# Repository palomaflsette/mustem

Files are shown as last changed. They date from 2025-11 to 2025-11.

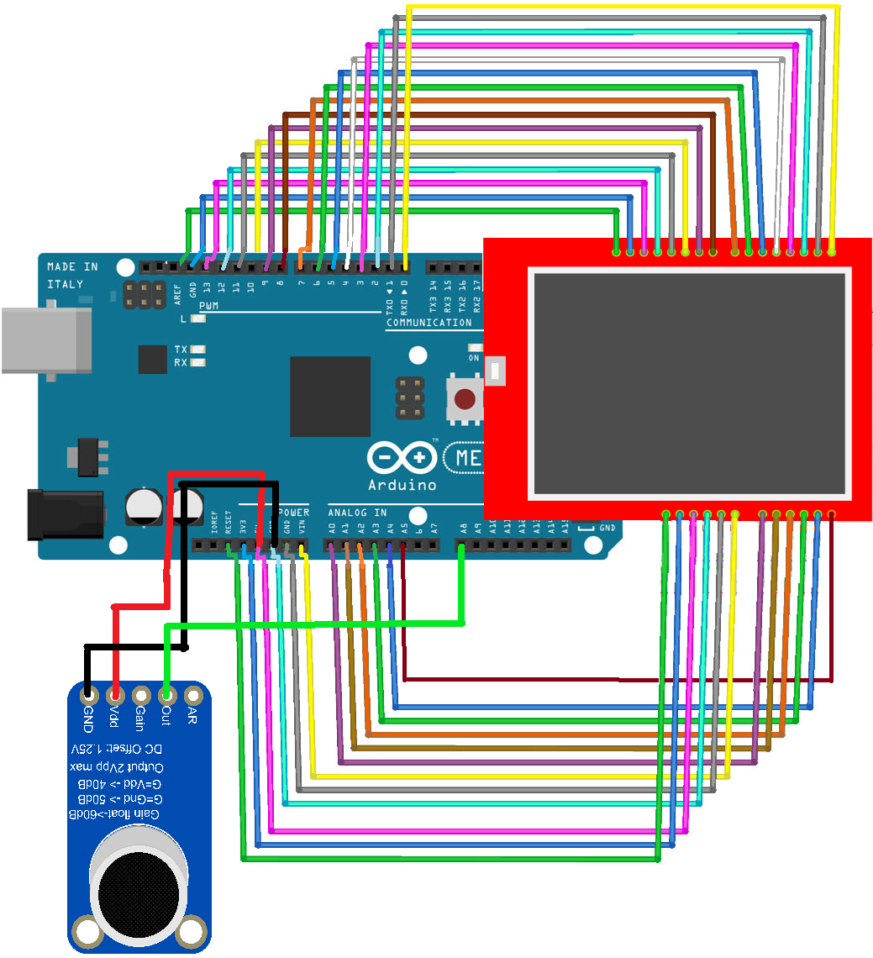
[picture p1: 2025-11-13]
hardware/schematics/mega_LCD_eletreto.png

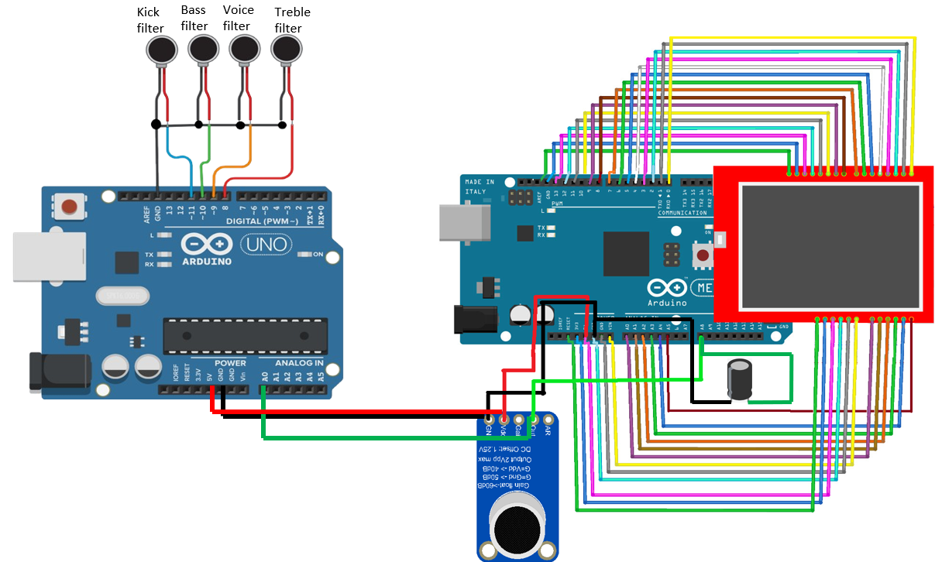
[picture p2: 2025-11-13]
hardware/schematics/integrated_system.png

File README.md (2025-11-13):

<div align="center">

# 🎵 MUSTEM
### Music - Multisensory Emotional Translation

**A scientifically-grounded dual-modality system for vibrotactile and visual translation of music as an assistive technology**






**[📖 Documentation](#-documentation) • [🚀 Quick Start](#-quick-start) • [🎥 Demos](#-video-demonstrations) • [📚 Research](#-research-paper)**

</div>

---

## 📑 Table of Contents

- [Overview](#-overview)
- [The Central Question](#-the-central-question)
- [System Architecture](#-system-architecture)
  - [Hardware Components](#hardware-components)
  - [Dual-Modality Design](#dual-modality-design)
- [Scientific Foundations](#-scientific-foundations)
  - [Stevens' Power Law](#1-stevens-power-law-psychoacoustic-scaling)
  - [Logarithmic Frequency Mapping](#2-logarithmic-frequency-mapping)
  - [Golden Ratio Phyllotaxis](#3-golden-ratio-phyllotaxis)
- [Repository Structure](#-repository-structure)
- [Getting Started](#-getting-started)
  - [Hardware Setup](#hardware-setup)
  - [Firmware Installation](#firmware-installation)
  - [Software Installation](#software-installation)
- [Video Demonstrations](#-video-demonstrations)
- [Research Paper](#-research-paper)
- [Technical Details](#-technical-details)
- [Bill of Materials](#-bill-of-materials)
- [License](#-license)
- [Citation](#-citation)
- [Acknowledgments](#-acknowledgments)

---

## 🎯 Overview

**MUSTEM** (Music - Multisensory Emotional Translation) is an open-source assistive technology that makes music accessible to deaf and hard-of-hearing individuals through complementary dual-modality translation:

- **Vibrotactile (FEEL):** 4-channel spatial frequency mapping for rhythm and foundation
- **Visual (SEE):** Mathematical color and pattern generation for structure and details

### Why MUSTEM?

- **430+ million** people worldwide are deaf or hard-of-hearing (WHO, 2023)
- Music represents **cultural and emotional exclusion**, not just auditory inaccessibility
- Current solutions (amplification, visual-only, vibration-only) have significant limitations
- **No integrated dual-modality approach** exists with scientific grounding

### Key Features

**Scientifically-grounded** - Based on Stevens' Power Law, Fletcher-Munson curves, and golden ratio  
**Real-time processing** - <60ms latency on affordable hardware  
**Affordable** - <$50 USD in components  
**Open-source** - Hardware, firmware, and software freely available  
**Validated** - Pilot study (N=7) with positive preliminary results  

---

## The Central Question

> **"Can deaf people *truly* experience music emotionally through non-auditory modalities?"**

**Our answer:** Musical experience is **relative to individual sensory capacity**. A deaf person experiencing music through tactile and visual modalities is not having an "inferior" experience—they're having an **authentic experience through their perceptual reality**.

Read our complete philosophical framework: **[docs/PHILOSOPHICAL_FRAMEWORK.md](docs/PHILOS_FRAMEWORK.md)**

### Core Arguments:

1. **Musical emotion emerges from pattern processing**, not specific sensory modality
2. **Deaf individuals have adapted sensory systems** with enhanced tactile and visual capabilities
3. **Validity is user-determined**, not defined by hearing-centric assumptions

---

## 🏗️ System Architecture

### Hardware Components
```
┌─────────────┐
│  Ambient    │
│   Sound     │
└──────┬──────┘
       │
       ▼
┌─────────────┐
│  Electret   │
│ Microphone  │
└──────┬──────┘
       │
       ├──────────────────────┬─────────────────────┐
       │                      │                     │
       ▼                      ▼                     ▼
┌─────────────┐      ┌─────────────┐      ┌─────────────┐
│  Arduino    │      │  Arduino    │      │   Python    │
│    UNO      │      │    Mega     │      │  Dashboard  │
│ (Tactile)   │      │  (Visual)   │      │ (Education) │
└──────┬──────┘      └──────┬──────┘      └─────────────┘
       │                     │
       ▼                     ▼
┌─────────────┐      ┌─────────────┐
│ 4× Motors   │      │ TFT LCD     │
│ (Wrists)    │      │  Display    │
└─────────────┘      └─────────────┘
```

### Dual-Modality Design

| Modality | Purpose | Hardware | Key Features |
|---|---|---|---|
| **Vibrotactile** | Rhythm & Foundation | 4× ERM motors | - Psychoacoustic band separation<br>- Stevens' Law scaling (n=0.67)<br>- <60ms latency<br>- Spatial discrimination (40cm) |
| **Visual** | Structure & Details | TFT LCD 320×240 | - Log-frequency color mapping<br>- Golden angle phyllotaxis (137.5°)<br>- Real-time FFT processing<br>- Nature-inspired patterns |

---

## 🔬 Scientific Foundations

MUSTEM is grounded in three core scientific principles:

### 1. Stevens' Power Law (Psychoacoustic Scaling)
```
I = S^n

Where:
  I = perceived intensity
  S = stimulus magnitude
  n = 0.67 (vibrotactile exponent)
```

**Why it matters:** Human perception is non-linear. Stevens' Law models this, ensuring weak signals are perceivable and strong signals are comfortable.

**Application in MUSTEM:**
- Vibrotactile intensity: `PWM = (RMS_energy)^0.67 × 255`
- Visual brightness: `Brightness = (FFT_magnitude)^0.67`

---

### 2. Logarithmic Frequency Mapping
```
s = 12 × log₂(f / 55Hz)
hue = (s mod 84) / 84 × 360°

Where:
  f = frequency in Hz
  s = semitone number
  hue = color hue (0-360°)
```

**Why it matters:** Musical intervals are logarithmic (12-tone equal temperament). Logarithmic mapping preserves octave equivalence—notes an octave apart map to similar colors.

**Application in MUSTEM:**
| Frequency | Semitone | Color |
|---|---|---|
| 40 Hz | 0 | Deep Red |
| 440 Hz (A4) | 40 | Green |
| 880 Hz (A5) | 52 | Green (similar) |
| 6000 Hz | 83 | Purple-Magenta |

---

### 3. Golden Ratio Phyllotaxis
```
θ[n] = n × 137.5° + ω(t)
r[n] = c × √n

Where:
  θ = angle of nth point
  r = radius of nth point
  137.5° = golden angle (360° / φ²)
  φ = golden ratio ≈ 1.618
```

**Why it matters:** Phyllotaxis (found in sunflowers, pinecones, galaxies) maximizes packing efficiency while maintaining aesthetic beauty.

**Application in MUSTEM:**
- Each audio frame adds a new point at golden angle rotation
- Radius grows as √n for uniform density
- Creates organic, temporally-evolving spiral

---

## 📁 Repository Structure
```
MUSTEM/
├── hardware/
│   ├── firmware/
│   │   ├── tactile_system/          # Arduino UNO code
│   │   └── visual_system/           # Arduino Mega code
│   ├── 3d_models/                   # 3D-printable enclosure
│   ├── schematics/                  # Wiring diagrams
│   └── bill_of_materials.md
│
├── software/
│   ├── dashboard/                   # Educational interface
│   └── visualization/               # Artistic visualization
│
├── docs/
│   ├── PHILOSOPHICAL_FRAMEWORK.md   # Core arguments
│   ├── TECHNICAL_DETAILS.md         # Deep dive
│   ├── USER_GUIDE.md                # How to use
│   └── ASSEMBLY_GUIDE.md            # How to build
│
├── research/
│   ├── MUSTEM_EHB2025_slides.pdf    # Published paper
│   └── MUSTEM_EHB2025_slides.pdf    # Conference slides

```

---

## 🚀 Getting Started

### Prerequisites

**Hardware:**
- 1× Arduino Mega 2560
- 1× Arduino UNO
- 1× TFT LCD Shield 2.4" (320×240)
- 4× ERM vibration motors (3.3V)
- 1× Electret microphone
- Jumper wires, breadboard
- 3D printer (optional, for enclosure)

**Software:**
- Arduino IDE 1.8+
- Python 3.8+
- Git

---

### Hardware Setup

1. **Clone repository:**
```bash
git clone https://github.com/palomafsette/MUSTEM.git
cd MUSTEM
```

2. **3D print enclosure** (optional):
```bash
# Files in hardware/3d_models/
# Use 0.2mm layer height, 20% infill
```

3. **Wire components:**
   - Follow diagram: `hardware/schematics/system_wiring.png`
   - Full guide: `docs/ASSEMBLY_GUIDE.md`

---

### Firmware Installation

#### Tactile System (Arduino UNO):
```bash
cd hardware/firmware/tactile_system/
# Open tactile_system.ino in Arduino IDE
# Select: Tools --> Board --> Arduino UNO
# Select: Tools --> Port --> [your port]
# Upload
```

#### Visual System (Arduino Mega):
```bash
cd hardware/firmware/visual_system/
# Open visual_display_fft.ino in Arduino IDE
# Install required libraries:
#   - Adafruit GFX
#   - Adafruit TFT
#   - arduinoFFT
# Select: Tools --> Board --> Arduino Mega 2560
# Upload
```

**See:** `hardware/firmware/README.md` for detailed instructions

---

### Software Installation

#### Dashboard (Educational Interface):
```bash
cd software/dashboard/
python3 -m venv venv
source venv/bin/activate  # Windows: venv\Scripts\activate
pip install -r requirements.txt
python mustem_assistive_dashboard.py
```

#### Artistic Visualization:
```bash
cd software/visualization/
pip install -r requirements.txt
python mustem_artistic_visualization.py [audio_file.wav]
```

**See:** `software/README.md` for usage details

---

## 🎥 Video Demonstrations

Feel free to visit the Youtube MUSTEM Channel: [`https://www.youtube.com/@Mustem7`](https://www.youtube.com/@Mustem7)

---

## 📚 Research Paper

**Title:** MUSTEM: A Dual-Modality System for Vibrotactile and Visual Translation of Music as an Assistive Technology

**Published:** EHB 2025 - 13th International Conference on e-Health and Bioengineering  
**Award:** Strong Accept  
**Authors:** Paloma Sette, Maria Werneck, William Barbosa, Ana Loubacker

**Read the paper:** [`research/paper_MUSTEM_EHB2025.pdf`](research/paper_MUSTEM_EHB2025.pdf)  
**View slides:** [`research/MUSTEM_EHB2025_slides.pdf`](research/MUSTEM_EHB2025_slides.pdf)

---

## 🔧 Technical Details

### Vibrotactile System

**Signal Processing:**
- EMA envelope detection (α_attack=0.3, α_decay=0.1)
- Stevens' scaling: I = S^0.67
- PWM output: 30-255 (8-bit)
- Latency: <60ms (<100ms perceptual threshold)

**Frequency Bands:**
| Band | Range | Purpose | Wrist |
|---|---|---|---|
| Kick | 20-80 Hz | Main beats | Left |
| Bass | 80-300 Hz | Foundation | Left |
| Voice | 300-2000 Hz | Melody | Right |
| Treble | 2k-8k Hz | Texture | Right |

**Perceptual Grounding:**
- Fletcher-Munson aligned bands
- Spatial discrimination: 40cm (>5cm JND)
- Just-noticeable difference: 3 PWM levels

---

### Visual System

**Frequency-to-Color Mapping:**
- 9 bands: sub-bass → treble
- Logarithmic spacing (12-tone equal temperament)
- Preserves octave equivalence

**Pattern Generation:**
- Golden angle: θ = 137.5°
- Fermat spiral: r = c√n
- Real-time FFT: 512-point, 4 kHz sampling

**Complete mapping:** `docs/TECHNICAL_DETAILS.md#visual-mapping`

---

## 💰 Bill of Materials

| Component | Qty | Price (USD) | Link |
|---|-----|---|---|
| Arduino Mega 2560 | 1 | $15 | [Link](https://store.arduino.cc) |
| Arduino UNO | 1 | $10 | [Link](https://store.arduino.cc) |
| TFT LCD Shield 2.4" | 1 | $12 | [Link](example.com) |
| ERM Vibration Motor 3.3V | 4 | $8 | [Link](example.com) |
| Electret Microphone | 1 | $2 | [Link](example.com) |
| Jumper Wires & Breadboard | 1 | $5 | [Link](example.com) |
| **TOTAL** | | **~$52** | |

**See:** `hardware/bill_of_materials.md` for complete list with supplier links

---

## 📜 License

This project is licensed under the **MIT License** - see [LICENSE](LICENSE) file for details.

**TL;DR:** You can use, modify, and distribute this work freely, even commercially, as long as you include the original copyright notice.

---

## 📖 Citation

If you use MUSTEM in your research, please cite:
```bibtex
@inproceedings{sette2025mustem,
  title={MUSTEM: A Dual-Modality System for Vibrotactile and Visual Translation of Music as an Assistive Technology},
  author={Sette, Paloma and Werneck, Maria and Barbosa, William and Loubacker, Ana},
  booktitle={13th International Conference on e-Health and Bioengineering (EHB)},
  year={2025},
  organization={IEEE}
}
```

---

## Acknowledgments

- **PUC-Rio** - Pontifícia Universidade Católica do Rio de Janeiro
- **EHB 2025** - [International Conference on e-Health and Bioengineering](https://www.ehbconference.ro/Home.aspx)
- **Deaf community** - For feedback and co-design input
- **Open-source contributors** - Arduino, Python, and maker communities

---

## 📧 Contact

**Paloma Sette** - Research Lead  
- Email: [pfls.sette@gmail.com](pfls.sette@gmail.com)  
- LinkedIn: [https://linkedin.com/in/paloma-sett](https://linkedin.com/in/paloma-sett)  

---

<div align="center">

**Making music universally accessible - not just hearing it differently, but experiencing it fully.**

🎵 430M+ potential beneficiaries worldwide 🌍

**[⭐ Star this repo](https://github.com/palomafsette/MUSTEM) • [🍴 Fork it](https://github.com/palomafsette/MUSTEM/fork) • [📣 Share it](https://twitter.com/intent/tweet?text=Check%20out%20MUSTEM)**

</div>

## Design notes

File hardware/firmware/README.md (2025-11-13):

# MUSTEM Firmware

## Overview

This directory contains Arduino firmware for both subsystems:
- **Tactile System** (Arduino UNO): 4-channel vibrotactile control
- **Visual System** (Arduino Mega): FFT analysis and TFT display

## Installation

### Tactile System

1. Open `tactile_system/tactile_system.ino` in Arduino IDE
2. Install required libraries: (none required, uses built-in)
3. Select **Board:** Arduino UNO
4. Select **Port:** [your port]
5. Click **Upload**

### Visual System

1. Open `visual_system/visual_display_fft.ino` in Arduino IDE
2. Install required libraries:
```
   Sketch → Include Library → Manage Libraries
   Search and install:
   - Adafruit GFX Library
   - Adafruit TFT LCD Library
   - arduinoFFT
```
3. Select **Board:** Arduino Mega 2560
4. Select **Port:** [your port]
5. Click **Upload**

## Configuration

See comments in each `.ino` file for parameter tuning.

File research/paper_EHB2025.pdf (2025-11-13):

## MUSTEM: A Dual-Modality System for Vibrotactile and Visual Translation of Music as an Assistive Technology

Paloma Sette¹*[0009-0009-8948-6548], Maria Werneck¹²[0009-0006-1477-9272], William Barbosa¹[0000-0002-

6537-608X], Ana Loubacker³[0000-0002-4371-3356]

### 1 Pontifical Catholic University of Rio

de Janeiro, Rio de Janeiro, Brazil

2 Vrije Universiteit Amsterdam, Amsterdam, Netherlands

### 3 Rio de Janeiro State University, Rio

de Janeiro, Brazil

paloma.sette@aluno.puc-rio.br (pfls.sette@gmail.com), maria.werneck.uni@gmail.com,

willsbarbosa@gmail.com,
loubacker@gmail.com

Abstract. The emotional and structural experience of music remains a significant accessibility challenge for the deaf and hard of hearing community. This paper introduces MUSTEM (Multisensorial Emotional Translation), a novel system designed to translate music into a rich, coherent, and scientifically-grounded sensory experience. We present a dual-modality approach addressing this challenge through two interconnected components. First, a low-cost, portable hardware prototype that performs real-time audio analysis, mapping distinct frequency bands (sub-bass, bass, mid-range, treble) to a four-channel vibrotactile system, allowing users to feel the music's rhythmic and foundational structure. Second, to overcome the processing limitations of embedded hardware, we developed a high-fidelity software simulation that demonstrates the full potential of the visual translation. This assistive dashboard decodes musical components—such as rhythm, harmony, and frequency spectrum—into an intuitive and educational visual interface. MUSTEM offers a comprehensive framework for sensory substitution, presenting a viable and accessible pathway for the deaf community to experience music not just as vibration, but as a structured, substantiated and emotionally resonant visual and tactile language. Preliminary feedback from seven deaf users suggests the system's spatial vibrotactile mapping is perceptible and engaging. All source code and hardware designs are released as open-source. Video demonstrations¹ and open-source code² are available on the project's official channel.

Keywords Assistive Technology · Sensory Substitution · Music Visualization · Vibrotactile Feedback · Psychoacoustics · Human-Computer Interaction

### 1 Introduction

Music is a fundamental aspect of human culture, serving as a powerful medium for emotional expression, social connection, and cognitive enrichment. However, this universally cherished experience remains largely inaccessible to the global deaf and hard of hearing (DHH) community, which comprises over 430 million people. This exclusion represents not just a sensory deficit but a significant barrier to cultural and social participation. While the auditory channel is unavailable, the human brain’s remarkable plasticity allows for the development of alternative sensory pathways.

### 1 MUSTEM project video demonstrations: https://www.youtube.com/@Mustem-n6z

² GitHub repository: https://github.com/palomaflsette/sensory-translation (includes Arduino firmware, Python visualization engine, and 3D models)

This creates a compelling need for effective sensory substitution technologies capable of translating the complex, multi-layered information of music into a language that can be perceived through other senses, such as touch and sight.
Current technological approaches to this challenge often focus on conveying rhythm through vibrotactile feedback. While valuable, many existing solutions are prohibitively expensive and inaccessible, and frequently overlook the rich harmonic, melodic, and timbral content that constitutes the emotional core of music. The visual components, when present, tend to be abstract displays of light that lack a clear, structural, or educational meaning, leaving a gap for a system that offers a more holistic and informative translation. There is a clear need for an integrated, low-cost framework that provides a multi-modal (tactile and visual) translation of music that is both structurally coherent and emotionally resonant, grounded in scientific principles of psychoacoustics.
To address this gap, we present MUSTEM (Multisensorial Emotional Translation), a dual-modality system designed to translate music into a scientifically-grounded language of vibrotactile and visual stimuli.
Our approach is twofold. First, we developed a self-contained, portable hardware prototype to validate the core concept. This device performs real-time audio analysis and maps four distinct psychoacoustic frequency bands to a corresponding four-channel vibrotactile system. Second, to demonstrate the full potential of the visual translation without the constraints of embedded hardware, we developed a high-fidelity software simulation. This simulation features an assistive dashboard designed to educate users about musical structures. This paper details the architecture of MUSTEM, presents its methodology for sensory mapping, and demonstrates its potential as both an accessible therapeutic tool and a new medium for artistic experience. The system's real-time performance is demonstrated in the supplementary video.

### 2 Related Work

The field of sensory substitution for the deaf and hard of hearing (DHH) community has seen notable advancements, primarily centered on vibrotactile feedback systems. Devices such as vests and wristbands have demonstrated success in conveying the rhythmic components of music, translating beats and tempo into haptic sensations. Prominent examples include projects like the "Vest" by Eagleman and MuSS-Bits++, which focus on translating sound into vibrations and, in some cases, simple visual cues. While effective in representing rhythm, these solutions often present two main limitations: they can be cost-prohibitive, and they tend to underemphasize the rich harmonic, melodic, and timbral information of music in their visual feedback. MUSTEM differentiates itself by integrating a multi-band, psychoacoustically-mapped vibrotactile system with a dualpurpose visual interface designed for both education and artistic expression, all within a low-cost, accessible framework.
While Eagleman's Vest [4] and MuSS-Bits++ focus primarily on rhythm, they lack integrated visual feedback for harmonic/melodic content. MUSTEM differentiates itself through: (1) psychoacoustically-grounded 4-band spatial mapping, (2) an educational visual dashboard explaining musical structure, and (3) a low-cost, replicable design (<$50 USD vs. $2000+ commercial alternatives).

### 3 Methodology

The MUSTEM system was developed through a dual-pronged approach: a physical proof-ofconcept prototype to validate the hardware and real-time processing, and a high-fidelity software simulation to explore the full potential of the user experience.
The core philosophy of MUSTEM is to create sensory translations grounded in scientific principles rather than arbitrary mappings. Our approach integrates three foundational pillars:
- Psychoacoustic loudness scaling: Vibrotactile intensity follows Stevens' Power Law [2] (exponent n=0.67), modeling the logarithmic relationship between stimulus magnitude and human perception.

- Musically-consonant frequency mapping: Color assignment uses logarithmic mapping based on 12-tone equal temperament, ensuring octave equivalence and harmonic visual relationships. Nature-inspired generative patterns: Visual elements employ Golden Ratio

phyllotaxis spirals and Cymatics-inspired percussion rendering for organic aesthetic resonance. This synthesis enables translations that preserve musical structure while maintaining perceptual naturalness.

### 3.1 System Architecture

System's architecture follows a clear data flow. Ambient sound is captured by an electret microphone and processed by a microcontroller (Arduino Mega 2560). The analysis engine separates the audio signal into distinct features, which are then mapped to two parallel output modalities: (1) a 4-channel vibrotactile system controlled by an Arduino UNO, and (2) a real-time visual display. For high-fidelity demonstration, the visual translation component was also developed as a standalone Python application, which processes a .wav file to render the advanced visual dashboard.

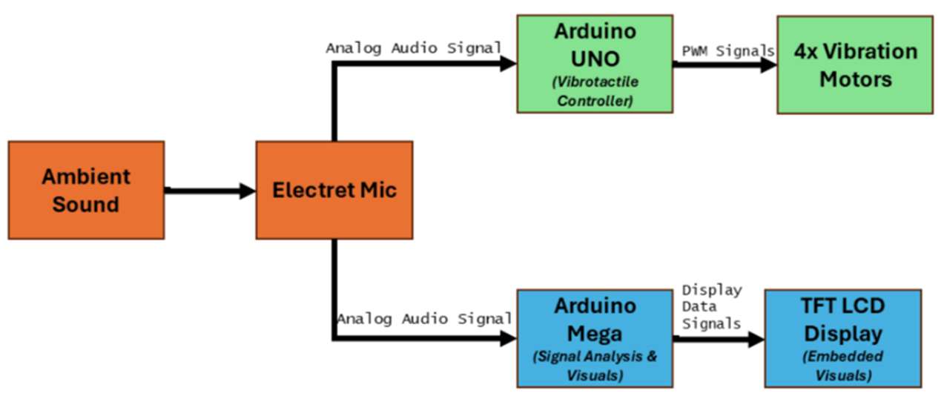
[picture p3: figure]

Fig. 1. System architecture block diagram. The analog audio signal from the electret microphone is processed in parallel by two microcontrollers: an Arduino Mega dedicated to signal analysis and visual rendering on the TFT display, and an Arduino UNO that independently controls the 4-channel vibrotactile system.
Arduino Mega 2560 Performs FFT-based spectral analysis (512-point, 4 kHz sampling) for the visual display on the TFT shield. Arduino UNO runs lightweight EMA-based envelope detection for the vibrotactile system to maintain <100ms haptic latency. Section 3.3 describes the UNO's heuristic approach. For FFT implementation details on the Mega, see Section 3.4 (Visual Mapping).

### 3.2 Hardware Prototype and Vibrotactile System

The physical implementation of MUSTEM is a self-contained proof-of-concept prototype, shown in Fig. 1. The system is housed in a custom 3D-printed icosahedral chassis designed to be both aesthetically engaging and functional, containing the dual-microcontroller architecture and the embedded TFT display for the portable visualizer.

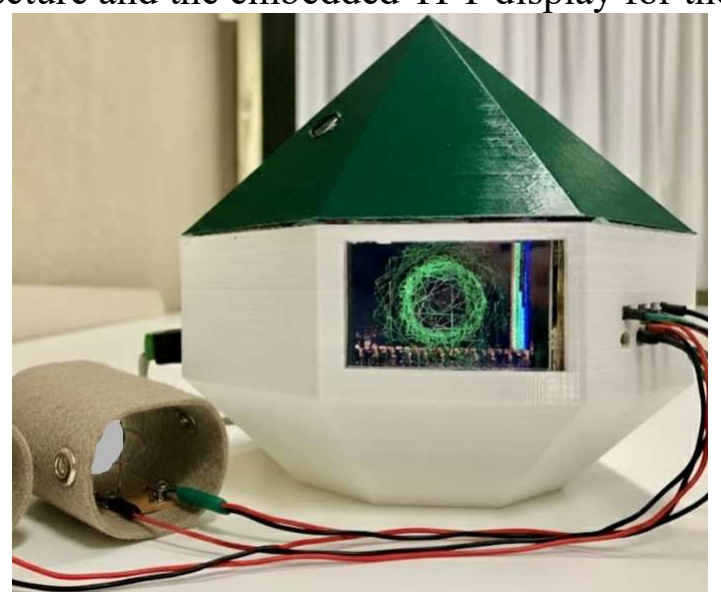
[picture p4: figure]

Fig. 2. The MUSTEM physical proof-of-concept prototype, featuring a custom 3D-printed icosahedral chassis housing the dual-Arduino architecture and the embedded TFT display.

The core of the prototype's tactile feedback is a 4-motor system. This design choice moves beyond simple rhythmic feedback by dedicating each actuator to a specific, psychoacoustically relevant frequency band. This separation allows the user to feel the distinct layers of a musical piece, translating the song's structure into a spatially distributed tactile experience. The frequency bands are defined in the embedded firmware as follows:
const int motorKickPin = 11;//KICK (20-80Hz) - Main beats const int motorBassPin = 10; //BASS(80-300Hz)
const int motorVoicePin = 9 ; //VOICE/MELODY (300-2kHz) const int motorTreblePin = 8; //TREBLE (2k-8kHz)

### 3.3 Heuristic Audio Analysis (Arduino UNO – Vibrotactile)

This controller runs on an Arduino UNO and performs real-time, FFT-free analysis to drive a four-channel vibrotactile interface. The UNO handles haptics independently from the Arduino Mega/TFT pipeline, where FFT is used only for the visualizer.

Band allocation and pins. Each actuator is permanently assigned to a psychoacoustic band and mapped to a PWM pin:
- Kick 20–80 Hz → D11;
- Bass 80–300 Hz → D10;
- Voice/Melody 300–2 kHz → D9;
- Treble 2–8 kHz → D8.
The microphone is read on A1; a front-panel LED on D3 mirrors the per-frame maximum PWM as a global activity cue. This spatial separation lets users feel distinct musical layers.

Pipeline overview. The UNO uses a lightweight, event-driven envelope analysis with first-order IIR (EMA) filters to approximate band energy and transients under tight 8-bit constraints:
1. DC offset calibration. At boot, the baseline b is estimated from several quiet reads. Each ADC sample is centered and rectified: x
= |x

− b|.

### 2. Full-band rectified envelope. A slow EMA tracks the overall amplitude:

a

= (1 − α) · a{}

+ α · x

### 3. Four temporal “quasi-bands” (EMAs). Instead of spectral filtering, band

selectivity is temporal: slower EMAs emphasize low-frequency content; faster EMAs capture high-frequency transients. For k ∈ {Kick, Bass, Voice, Treble}:
E

{()} = (1 − α) · E{}

{()} + α · a

with α ≪ α < α ≪ α . Firmware values: α = 0.08, α =
0.30, α = 0.45, α = 0.80.

### 4. Event cues (optional). Lightweight detectors add structure (e.g., kick-boost on sharp

rises; hi-hat when treble is high while bass is low). Band level is:
level ← E

{()} + cue

### 5. Activation & hysteresis. For each band, a fixed threshold in ADC units gates the

motor; EMA dynamics provide hysteresis: T = 45; T = 58; T = 52; T = 30.

### 6. Perceptual compression → PWM. The normalized surplus passes through a

compressive power law to approximate vibrotactile loudness:

I

= [clip(norm(E

), 0,1)]⁽)
,
with γ ∈ [0.7,0.9] (e.g., kick ≈ 0.9, bass ≈ 0.7, voice ≈ 0.8). PWM limits ensure salience without discomfort: min = 80; max (Sub/Bass/Voice/Treble) = 255/240/200/180.

Cadence & latency. The loop reads A1, updates EMAs/PWM, and sleeps ≈ 8 ms; a compact debug line is printed every ≈ 120 ms. End-to-end haptic latency stays within ~100 ms, coordinated with the visual pipeline. Rationale. EMA banks emulate coarse bandpass behavior with O(1) compute and negligible RAM, preserving musical structure (beats, spectral layers) on constrained hardware.

Contrast with the Mega/TFT path. The visual analyzer on the Arduino Mega 2560 runs independently and does use FFT (e.g., 4 kHz sampling, 512-point Hamming, μ+3σ peakpicking, parabolic interpolation) for color/pattern mapping; none of this runs on the UNO. The split keeps haptics responsive while enabling richer visuals.

Table 1. Implementation summary (pins & parameters)
Subsystem | Setting
Mic input | A1 (single-ended), baseline from 150 reads (~3 ms spacing)
LED activity | D3 (PWM of per-frame max across bands)
Motors (PWM) | D11 Kick (20–80 Hz), D10 Bass (80–300 Hz), D9 Voice (0.3– 2 kHz), D8 Treble (2–8 kHz)
EMA (α) | Kick 0.08; Bass 0.30; Voice 0.45; Treble 0.80
Thresholds | Kick 45; Bass 58; Voice 52; Treble 30 (ADC units)
Intensity floor | 80 (PWM min)
Band maxima | Sub 255; Low-mid 240; Voice 200; Treble 180
Compression (γ ) | Kick ≈ 0.9; Bass ≈0.7; Voice ≈0.8; Treble ≈ 0.8–0.9
Loop cadence | 8 ms sleep; debug line each ≈120 ms

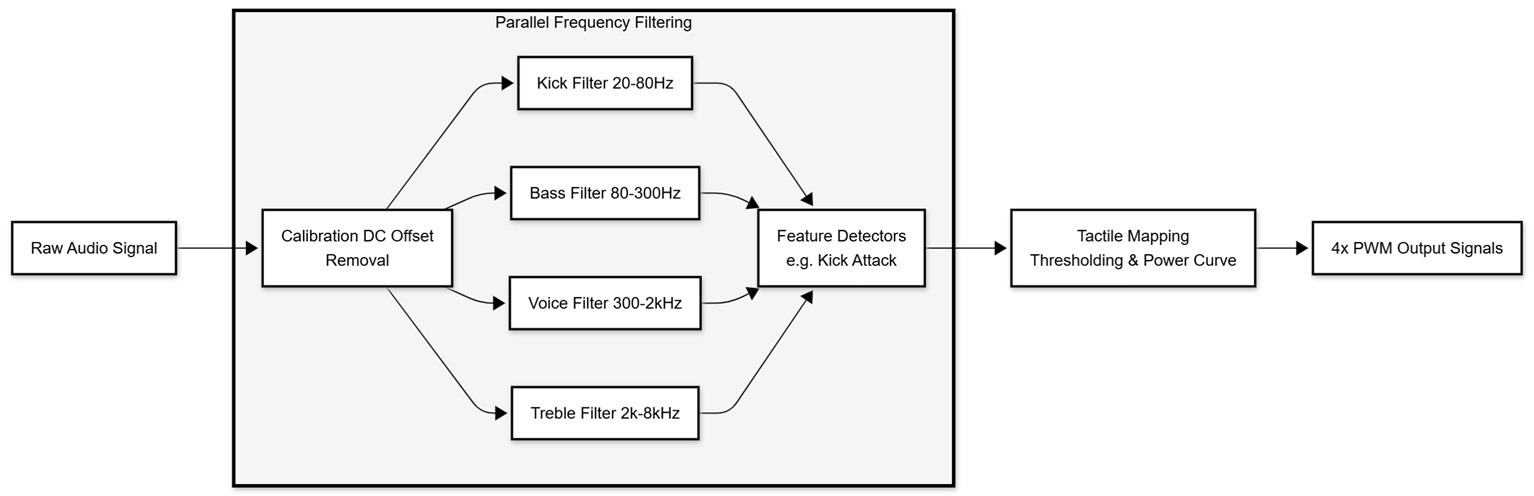
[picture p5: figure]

Fig. 3. Data-flow diagram of the heuristic audio analysis pipeline implemented on the embedded prototype. The process includes parallel filtering, event detection, and non-linear mapping to generate the final PWM signals for the vibrotactile system.

### 3.4 Visual Mapping and Display System (Arduino Mega & LCD Shield TFT)

The visual component translates audio features into real-time graphical representations optimized for perceptual interpretation and aesthetic engagement.

Frequency-to-Color Mapping. We use a log-frequency to hue mapping aligned with 12-tone equal temperament (octave periodicity). Let
s = 12 log f
fref , f = 55Hz(A1), ℎue ≈ s mod

84
84 360°.
Thus, octaves of A occupy similar hues while intermediate notes shift smoothly around the color wheel. In practice, A1 (55 Hz) maps near red, A4 (440 Hz) near green-cyan, and A7 (3520 Hz) near magenta-violet. We keep HSV saturation ≈ 95% and value ≈ 90% to ensure visibility on the 320×240 RGB565 TFT. (Angles are approximate to accommodate display gamut and perceptual uniformity).

FFT Implementation. The visual pipeline uses a 512-point FFT with Hamming windowing at 4 kHz sampling rate, providing 7.8125 Hz frequency resolution. Peak detection employs μ + 3σ thresholding with parabolic interpolation for sub-bin accuracy. The complete FFT→ color mapping → rendering cycle executes in < 50ms, coordinated with the UNO's haptic output via shared audio input.

Phyllotaxis Winding Visualization. The central dynamic visualization employs Fermat's spiral (phyllotaxis pattern) based on the golden angle (φ ≈ 137.5°):

θ[n] = n × φ + ω(t) [angular position]
r[n] = c × √n [radial distance]
ω(t) = (f_detected / 440) * k [rotation speed modulation] where n is the point index, c is a scaling constant, and k is empirically tuned (0.05 rad/frame). Radius modulation reflects RMS amplitude:

R_spiral = R_base + (RMS / 50) × 25 [constrained 20-80 pixels]

This creates an organic, flower-like pattern that:
- Rotates faster for higher frequencies (perceptual motion-pitch coupling)
- Expands radially during louder passages (size-intensity mapping)
- Resets periodically (8-second cycles) to prevent visual clutter
The algorithm draws 12 points per frame (25 Hz), connecting every 5th point to create web-like connectivity structures.

Spectrum Analyzer. A 9-band psychoacoustic spectrum analyzer displays energy distribution across Fletcher-Munson aligned frequency bands [3,8]:

Table 2. Psychoacoustic Frequency Band Color Mapping

Band | Range | Center Freq | Visual Color
Sub-bass | 20-60 Hz | 40Hz | Deep Red
Bass (low) | 60-80 Hz | 70Hz | Orange
Bass (mid) | 80-110Hz | 95Hz | Yellow
Bass (upper) | 110-165Hz | 135Hz | Yellow-Green
Low-Mid | 165-360Hz | 250Hz | Green
Mid (Low) | 360-630 Hz | 500Hz | Cyan
Mid (Upper) | 630-960 Hz | 800Hz | Light-Blue
High-Mid | 960-2400 Hz | 1500Hz | Dark-Blue
Treble | 2400+ Hz | 6000Hz | Purple-Magenta
Bars employ gradient rendering (darker at base, brighter at peak) with vertical height proportional to band energy. IIR smoothing (α = 0.30) prevents bar flicker while maintaining transient response.

Waveform Display and Beat Indicator. A simulated waveform (not raw audio) reflects detected frequency and amplitude:

y[x] = A × sin(2π × x / λ + φ(t))
where: A = (RMS / 50) × H_wave [amplitude scaling]
λ = map(f, 100-2000 Hz → 20-80 pixels) [wavelength] φ(t) = cumulative phase increment

A beat indicator circle (8-pixel radius) pulses in synchrony with detected onsets, with expansion magnitude proportional to beat strength (Stevens' exponent n=0.67 [2] for perceptual scaling).

Real-Time Debug Overlay. A persistent overlay (5 Hz update) displays:
- Energy (E) vs. Threshold (T) for activity gating transparency
- Detected frequency in Hz (or "SILENT" state)
- Color swatch showing current frequency-hue mapping

This provides immediate feedback for technical validation and calibration.

Rendering Performance. The complete visual pipeline executes at:
- Phyllotaxis: 25 Hz (40ms intervals)
- Spectrum bars: 10 Hz (100ms intervals)
- Waveform: 20 Hz (50ms intervals)
- Debug overlay: 5 Hz (200ms intervals)

Staggered update rates optimize microcontroller load while maintaining perceptual smoothness. Total frame time: 45-55ms, leaving headroom for audio analysis (50ms) within the 100ms system budget.

System Integration. Figure 4 shows the complete MUSTEM prototype during frequency detection validation. The hardware consists of an Arduino Mega 2560 with TFT shield displaying real-time visualizations, while the laptop runs calibrated test tones (383 Hz visible on screen). The electret microphone (visible among the jumper wires) captures audio for FFT analysis, with results immediately rendered on the embedded display showing the phyllotaxis spiral and waveform visualization.

### 4 Results

The evaluation of the MUSTEM system was conducted by analyzing the performance of both the physical hardware prototype and the high-fidelity software simulations. The results demonstrate a successful translation of musical information into coherent tactile and visual outputs. Video demonstrations are available on the project’s official channel¹.

### 4.1 Hardware Prototype

The functional prototype (Figure 4) integrates:
- Microcontroller(1): Arduino Mega 2560 (ATmega2560 @ 16 MHz)
- Microcontroller(2): Arduino UNO
- Display: 320×240 TFT LCD (RGB565, SPI interface)
- Audio Input: Electret condenser microphone with analog preamplifier
- Processing: Real-time FFT and visual rendering (< 50ms latency).
- The vibrotactile path on the UNO (EMA-based, no FFT) maintains end-to-end latency < ~100 ms, consistent with the haptic budget defined in Section 3.3. The breadboard implementation demonstrates proof-of-concept feasibility with offthe-shelf components, totaling approximately $50 USD in materials. The hardware prototype successfully performs real-time audio analysis and translation on its self-contained, dual-microcontroller architecture. The 4-channel vibrotactile system provides immediate and distinct haptic feedback, allowing the user to clearly feel the separation between the low-frequency impact of the kick drum, the steady presence of the bassline, the central body of the melody, and the high-frequency transients of cymbals. The embedded TFT display renders a direct audio-to-visual mapping, showing geometric patterns and a basic spectrum analyzer. While the visual performance is constrained by the microcontroller's processing power, resulting in a lower frame rate and complexity, it effectively validates the core concept of a portable, low-cost device capable of real-time sensory translation. The findings from this prototype confirm the viability of the approach and establish the foundation for the high-fidelity simulations.

Complete Wearable System. Figure 4 shows the complete MUSTEM system including the wearable vibrotactile interface. The system consists of four vibrotactile actuators housed in custom 3D-printed wrist-worn enclosures, connected to the central processing unit. This distributed architecture enables users to experience distinct frequency bands spatially: sub-bass and bass on one arm, mid-range and treble on the other, creating an intuitive spatial mapping of musical structure.

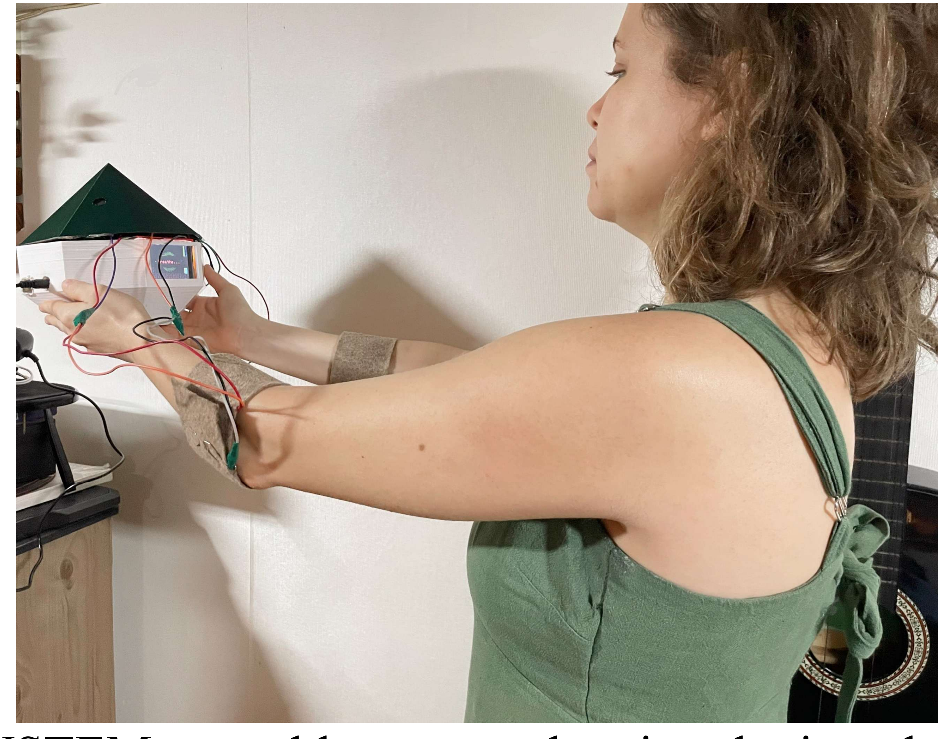
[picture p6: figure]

Fig. 4. Complete MUSTEM wearable system showing the icosahedral central unit with embedded display and four wrist-mounted vibrotactile actuators. The distributed configuration allows users to feel distinct frequency bands spatially mapped to each limb.

### 4.2 Technical Validation

Frequency detection accuracy was validated using calibrated pure sine tones (Online Tone Generator, Figure 5 background). The system correctly identified test frequencies within ±10 Hz across the 100-2000 Hz range, consistent with the theoretical FFT bin resolution (7.8125 Hz).

Visual inspection confirmed:
- Color mapping accuracy: 247 Hz tone produced green hue (expected: ~175° based on logarithmic mapping)
- Real-time responsiveness: Visual updates within 2-3 frames (~100ms) of tone changes
- Stability: No frequency flickering during sustained tones (hysteresis working as designed)

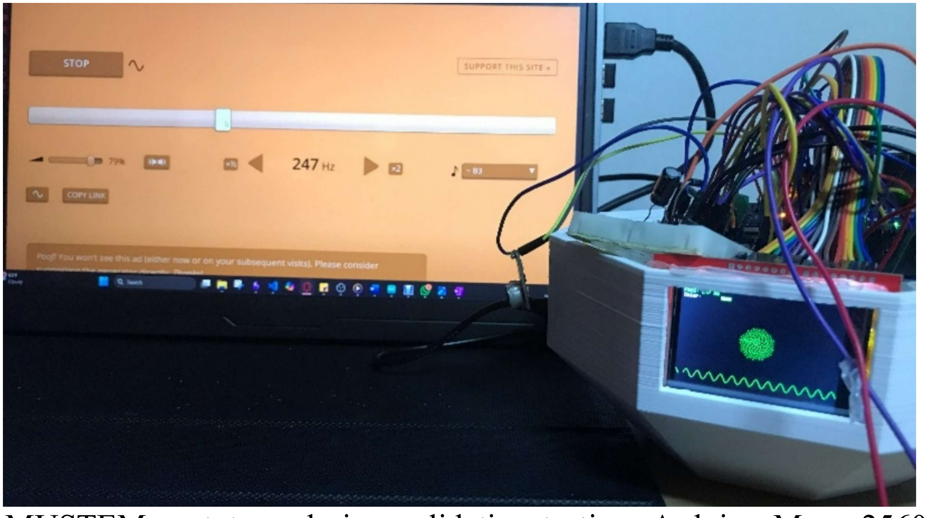
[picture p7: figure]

Fig. 5. MUSTEM prototype during validation testing. Arduino Mega 2560 with breadboard connections showing system complexity and electret microphone input. Embedded TFT display showing real-time frequency visualization (phyllotaxis spiral in cyan + waveform) responding to 383 Hz calibration tone (visible on laptop background). The color-coded jumper wires illustrate the multi-channel architecture connecting audio input, vibrotactile outputs (not shown), and visual display subsystems.

### 4.3 High-Fidelity Assistive Dashboard: An Educational Interface

The primary visual output of MUSTEM is conceptualized as an assistive tool designed not merely to visualize sound, but to make the core components of music comprehensible.

The assistive dashboard, shown in Figure 6, presents a multi-faceted analysis of the music in real-time. Each module on the dashboard is dedicated to translating a specific musical concept into an intuitive visual representation.

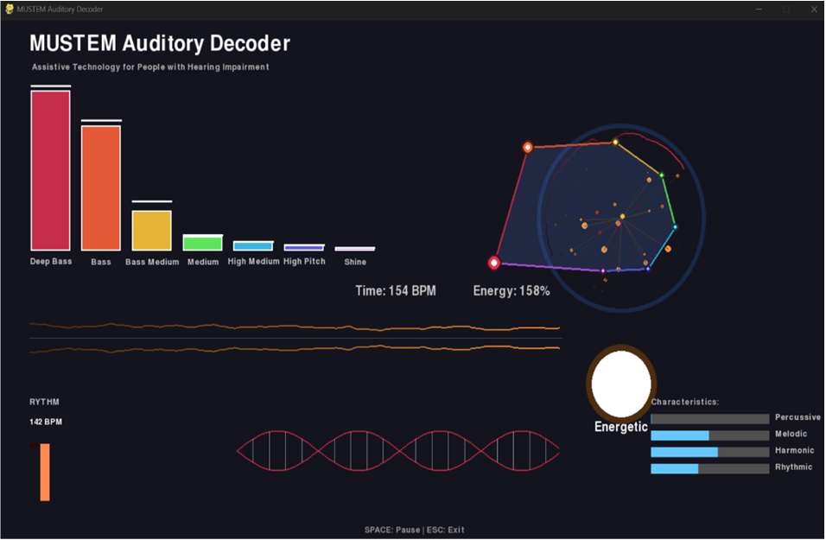
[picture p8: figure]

Fig. 6. The MUSTEM Auditory Decoder (software) showing a 9-band psychoacoustic spectrum (top-left), a polar spectral shape (top-right), historical energy (center), and modules for rhythm/emotion (bottom). Update rates are staggered (25/20/10/5 Hz) to balance responsiveness and compute.

### 4.4 Preliminary User Feedback

A preliminary informal evaluation was conducted with 7 deaf/hard-of-hearing participants (ages 22-45, 3 congenitally deaf, 2 with progressive hearing loss) during system development. Participants interacted with the prototype for 10-15 minutes while listening to three musical genres
(electronic, rock, classical). Qualitative Observations: | All participants successfully identified rhythmic patterns through the 4-channel
vibrotactile system within 2-3 minutes of familiarization; | 4/7 participants reported distinguishing between "heavy" (bass/kick) and "light" (treble)
sensations spatially ; | 3/7 participants expressed interest in the visual spectrum analyzer as an educational tool,
requesting labels/legends; | Positive feedback on the system's portability and wearability design;

Limitations: This was an unstructured pilot study without formal consent protocols or quantitative metrics. A comprehensive IRB-approved user study with validated assessment instruments (e.g., Quebec User Evaluation of Satisfaction with Assistive Technology - QUEST) is planned as immediate future work.

### 5 Discussion

The results presented in this paper demonstrate the viability of MUSTEM as a dual-modality sensory substitution system. The successful implementation of the hardware prototype validates the core concept of translating audio into a structured, four-channel vibrotactile experience. More significantly, the high-fidelity software simulation, particularly the MUSTEM Auditory Decoder, reveals the profound potential of the visual translation component. By moving beyond abstract light patterns and creating a structured, educational dashboard, the system offers a pathway for users not just to detect the presence of music, but to comprehend its fundamental components. The explicit visualization of frequency bands, rhythmic tempo, and emotional characteristics provides a rich informational layer that is often absent in existing assistive technologies, positioning MUSTEM as a potentially powerful tool for musical education and therapeutic applications within the DHH community.
While the results are promising, it is important to acknowledge the limitations of the current work. The preliminary user feedback (N=7) lacks statistical power and formal experimental controls—a comprehensive IRB-approved study is in progress; (2) The embedded prototype's visual rendering is constrained by microcontroller memory (8 KB RAM on Mega), limiting real-time complexity; (3) Long-term effects on musical comprehension/enjoyment require longitudinal assessment. Rigorous psychophysical testing (e.g., just-noticeable difference thresholds, channel discrimination accuracy) is essential before effective clinical deployment.
The system demonstrates functional performance across diverse musical genres, with its adaptive threshold mechanism providing resilience to moderate ambient noise. However, extremely noisy environments (crowded venues, outdoor festivals) may degrade performance due to low signal-to-noise ratios. Future work will explore AI-based noise filtering and adaptive parameter tuning, including machine learning models for real-time genre recognition and environment-aware processing.
Future work will focus on addressing these limitations and expanding the project's vision. We plan to integrate a more powerful embedded processor capable of performing real-time FFT analysis for both the vibrotactile and visual outputs on the portable device. A key objective is the development of a lightweight AI model for on-device instrument recognition, allowing the visual engine to render thematic representations automatically based on detected instrumental timbres. Finally, we will conduct structured user trials to gather feedback from the DHH community, which will be essential to refine the sensory mappings and validate MUSTEM as a legitimate therapeutic and educational tool.

### 6 Conclusion

This paper introduced MUSTEM, a dual-modality sensory substitution system designed to make music accessible to the deaf and hard of hearing. We presented the architecture and methodology of a functional hardware prototype with a 4-channel vibrotactile output and a high-fidelity software simulation that demonstrates an informative and educational approach to music visualization. By grounding its translation in psychoacoustic principles and exploring both assistive and creative applications, MUSTEM establishes a robust and accessible framework for future research and development in multi-sensory musical experiences. To promote accessibility and reproducibility, all system components— including Arduino firmware, Python software, and 3D-printable enclosure files—are released under [MIT license] at: https://github.com/palomaflsette/sensory-translation .

### References

1. Bello, J.P., Daudet, L., Abdallah, S., Duxbury, C., Davies, M., Sandler, M.B.: A tutorial on onset detection in music signals. IEEE Transactions on Speech and Audio Processing 13(5), 1035-1047 (2005)
2. Stevens, S.S.: On the psychophysical law. Psychological Review 64(3), 153-181 (1957). https://doi.org/10.1037/h0046162
3. Fletcher, H., Munson, W.A.: Loudness, its definition, measurement and calculation. Bell System Technical Journal 12(4), 377-430 (1933)
4. Eagleman, D.M., Novich, S.D.: Increasing sound awareness through the skin. Neuron 90(2), 237-240 (2016). https://doi.org/10.1016/j.neuron.2016.03.032
5. Correia, N.N., Masu, R., Altavilla, A.: Music and deafness: A collaborative performance to explore the aesthetics of vibration. In: Proceedings of the Audio Mostly Conference, pp. 1-8. ACM (2016)
6. Nanayakkara, S., Taylor, E., Wyse, L., Ong, S.H.: An enhanced musical experience for the deaf: Design and evaluation of a music display and a haptic chair. In: Proceedings of CHI, pp. 337-346. ACM (2009)
7. Branje, C., Maksimoski, M., Karam, M., Fels, D.I., Eagleson, R.: Vibrotactile display of music on the human back. In: Third International Conference on Advances in Computer-Human Interactions, pp. 154-159. IEEE (2010)
8. ISO 226:2023: Acoustics — Normal equal-loudness-level contours. International Organization for Standardization (2023)

### 9. Cooley, J.W., Tukey, J.W.: An algorithm for the machine calculation of complex Fourier

series. Mathematics of Computation 19(90), 297-301 (1965)

### 10. World Health Organization: World report on hearing. WHO, Geneva (2021)

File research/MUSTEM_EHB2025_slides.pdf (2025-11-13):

### The 13th International Conference on e-Health and Bioengineering – EHB 2025

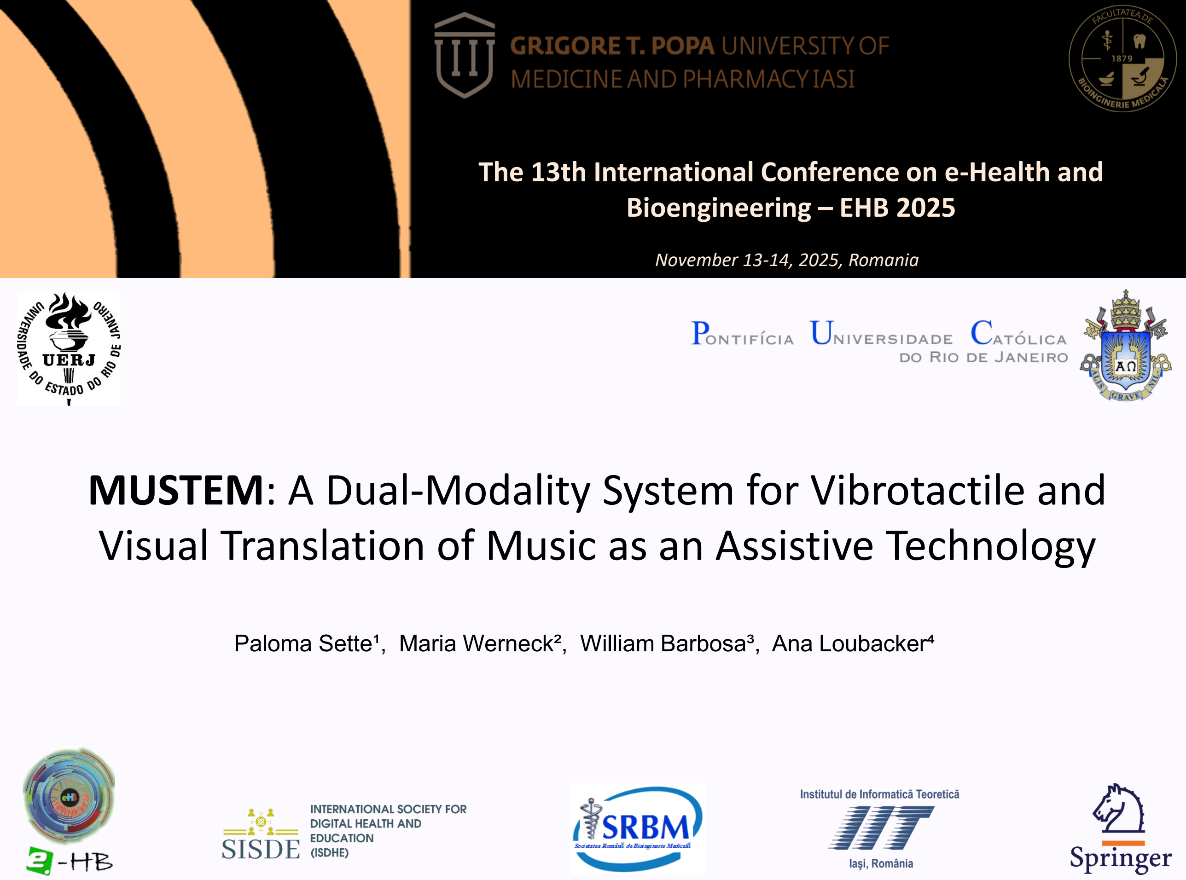
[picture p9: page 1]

# MUSTEM: A Dual-Modality System for Vibrotactile and Visual Translation of Music as an Assistive Technology

Paloma Sette¹, Maria Werneck², William Barbosa³, Ana Loubacker⁴

November 13-14, 2025, Romania

## 1. Background & Motivation

### THE CHALLENGE

430+ million deaf/HoH
people worldwide
(WHO, 2023)

Music = cultural/emotional exclusion

Emotional & structural
understanding

### CURRENT LIMITATIONS

Amplification → insufficient

Visual-only → lacks embodied exerience

Vibration-only → limited
frequency information

### RESEARCH GAP

No integrated dual-modality approach

How to create a
scientifically-grounded
system?

## 2. The Proposed Approach

### MUSTEM: Music - Multisensory Emotional Translation

Complementary dual-modality
- Vibrotactile → Rhythm & Foundation
- Visual → Structure & Details (non-arbitrary, math foundations)
- Low cost

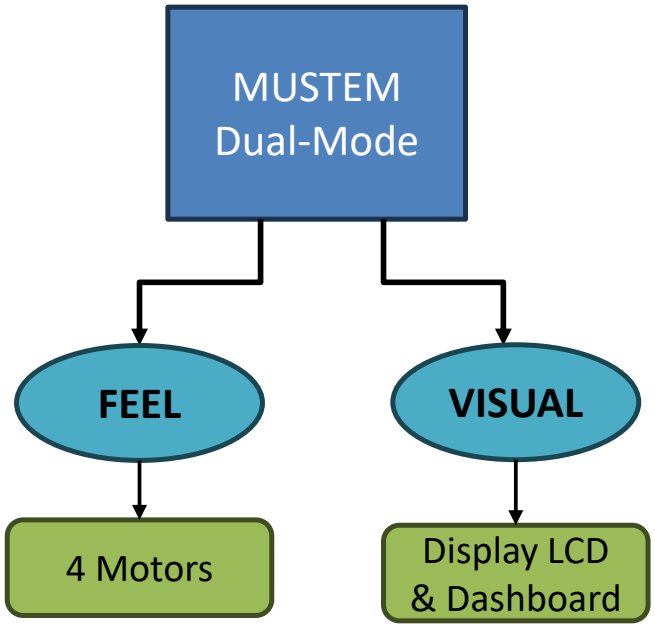
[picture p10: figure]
MUSTEM Dual-Mode; FEEL; VISUAL; Display LCD & Dashboard; 4 Motors

1x Arduino Mega 256
1x Arduino UNO
4x 3.3V vibration motor
1x Display LCD TFT Shield 2.4" 1x Electret Microphone
3D Printer

Main components:

## 3. Methodology

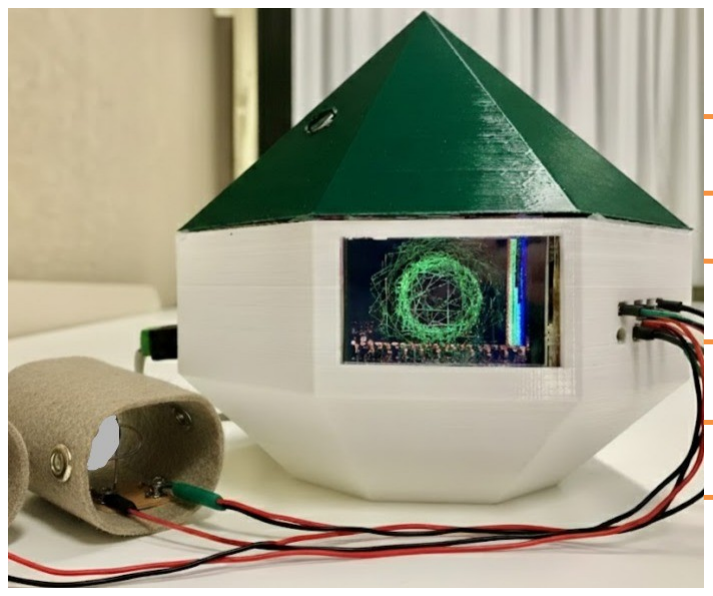
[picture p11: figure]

### 1. Psychoacoustic Loudness Scaling (Steven’s Power Law)

### 2. Musically-Consonant Frequency Mapping

### 3. Nature-Inspires Generative Patterns

## 3. Methodology

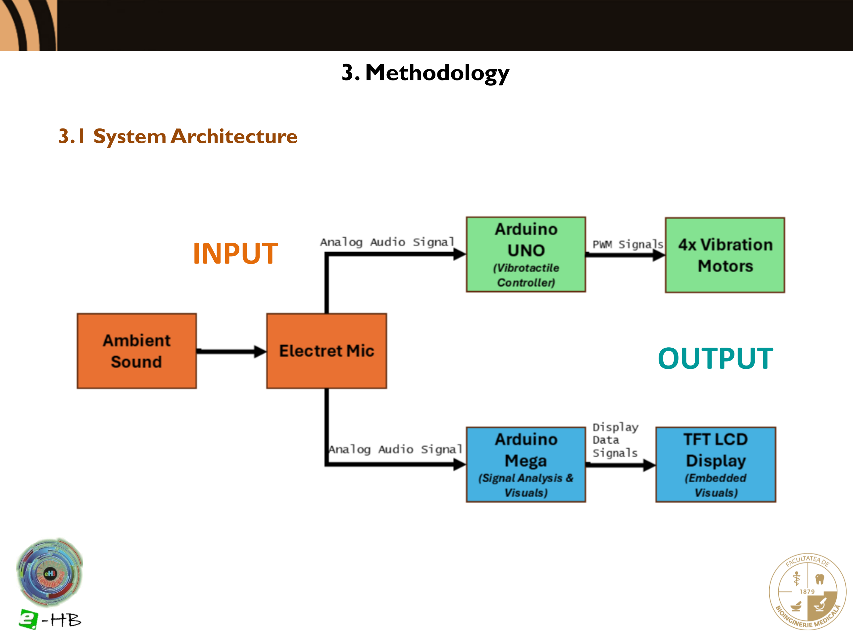
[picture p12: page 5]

### 3.1 System Architecture

# INPUT

# OUTPUT

## 3. Methodology

### 3.2 Hardware Prototype & Vibrotactile System (Heuristic Audio Analysis)

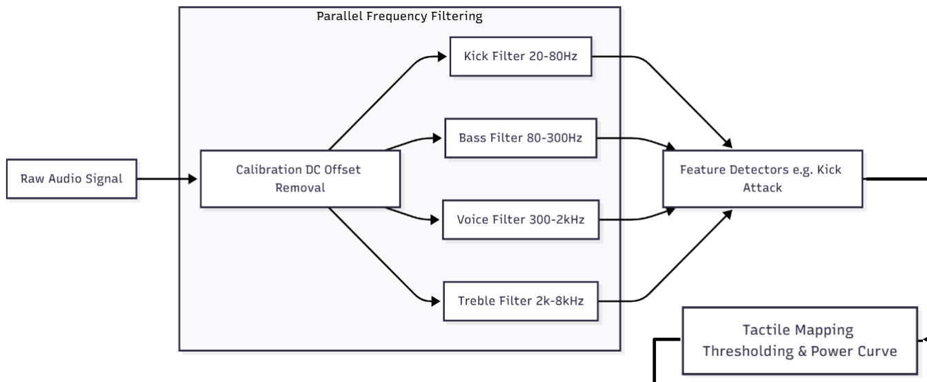
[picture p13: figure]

## 3. Methodology

### 3.2 Vibrotactile System (Heuristic Audio Analysis)

Kick
filter

Bass
filter

Voice
filter

Treble
filter

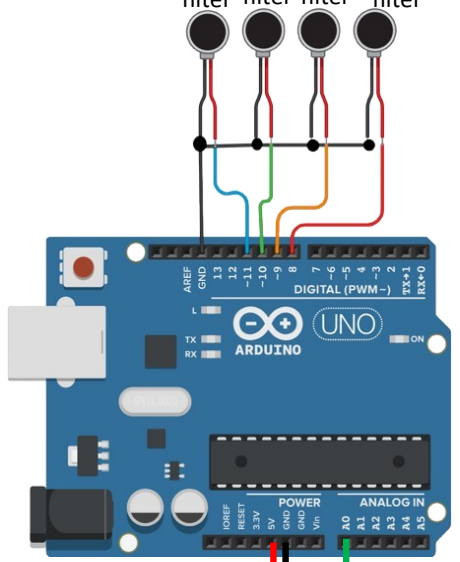
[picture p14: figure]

Signal Processing:

- EMA envelope (α = 0.3/0.1)
- Stevens' scaling: I = S^0.67
- PWM output: 30 − 255 (8 − bit)
- Latency: < 60ms

Perceptual Grounding:

- Fletcher-Munson aligned bands
- Spatial discrimination: 40cm
- Just-noticeable difference: 3 PWM

## 3. Methodology

### 3.2 Vibrotactile System (Heuristic Audio Analysis)

Kick
filter

Bass
filter

Voice
filter

Treble
filter
Frequency bands:
- Kick (main beats) → 20 – 80Hz
- Bass | → 80 – 300Hz
- Voice/Melody | → 300 – 2kHz
- Treble | → 2kHz – 8kHz

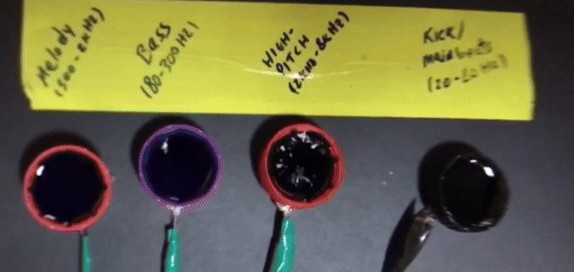
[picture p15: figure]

## 3. Methodology

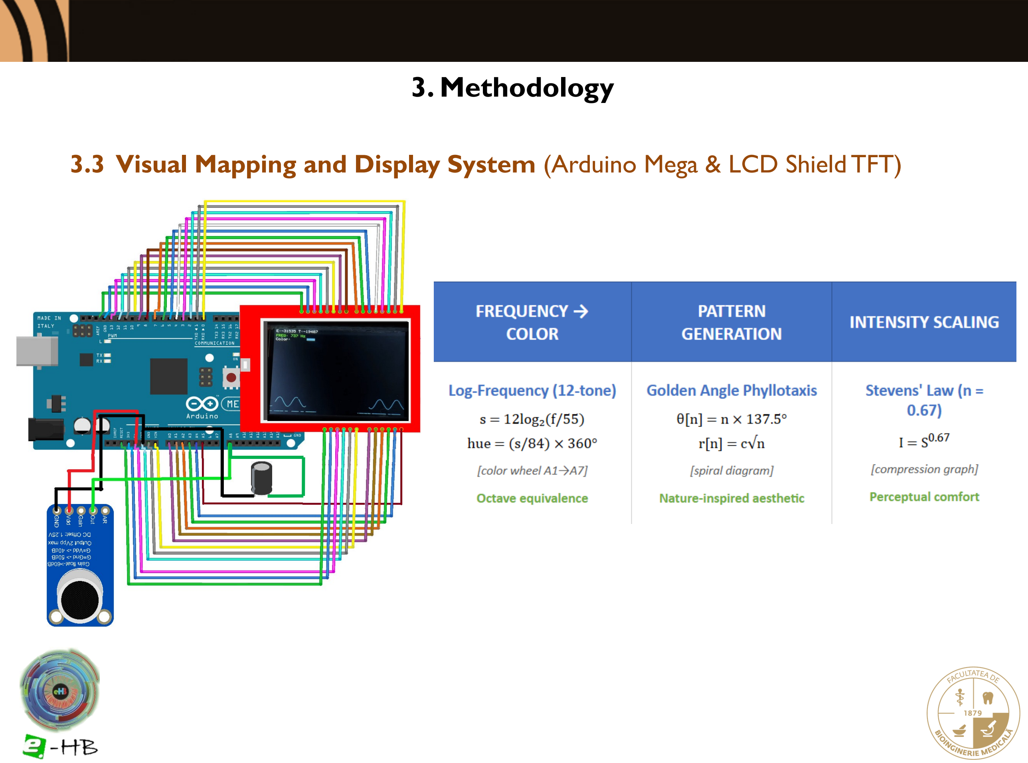
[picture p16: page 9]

### 3.3 Visual Mapping and Display System (Arduino Mega & LCD Shield TFT)

## 3. Methodology

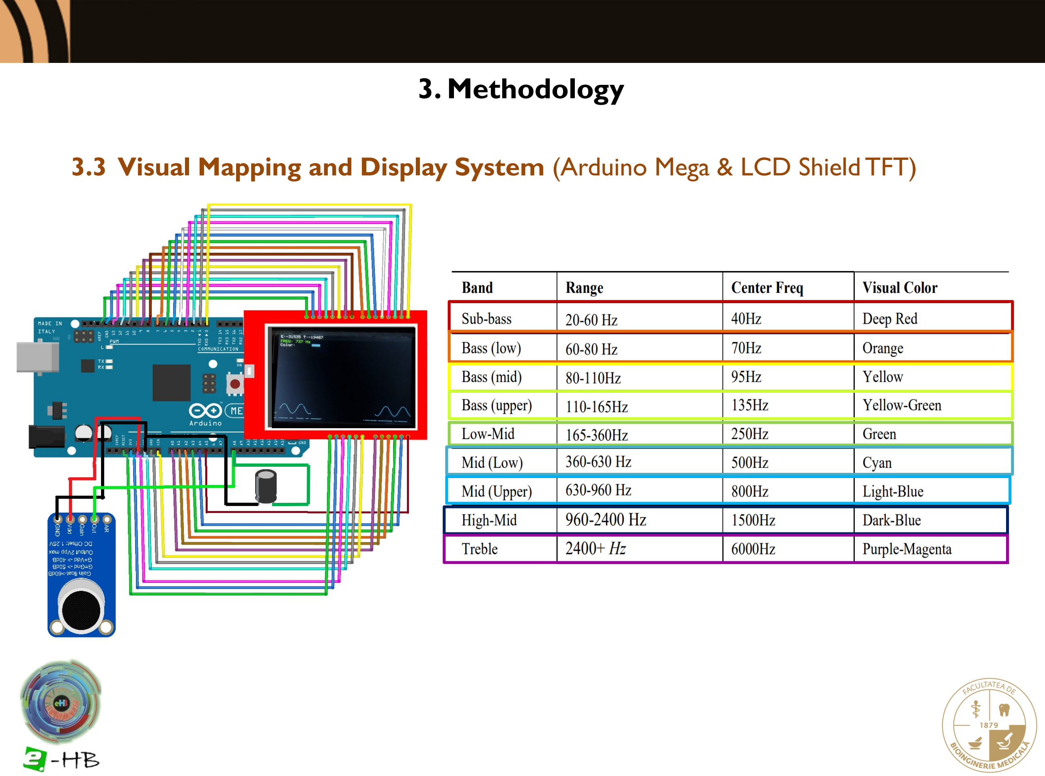
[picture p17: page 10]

### 3.3 Visual Mapping and Display System (Arduino Mega & LCD Shield TFT)

## 4. Results

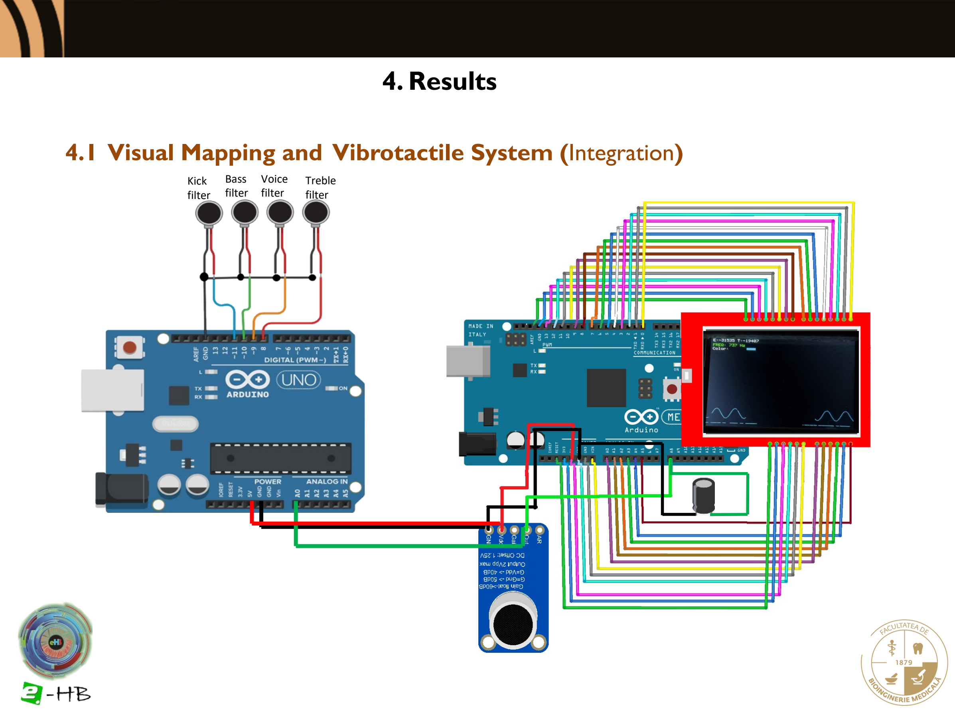
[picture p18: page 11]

### 4.1 Visual Mapping and Vibrotactile System (Integration)

Kick
filter

Bass
filter

Voice
filter

Treble
filter

## 4. Results

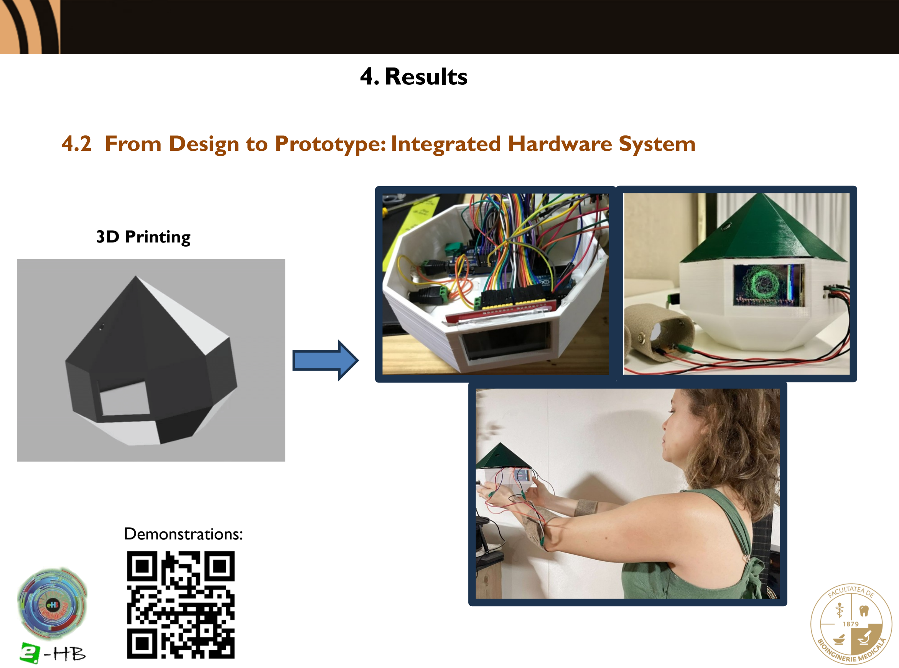
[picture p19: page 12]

### 4.2 From Design to Prototype: Integrated Hardware System

Demonstrations:

3D Printing

## 4. Results

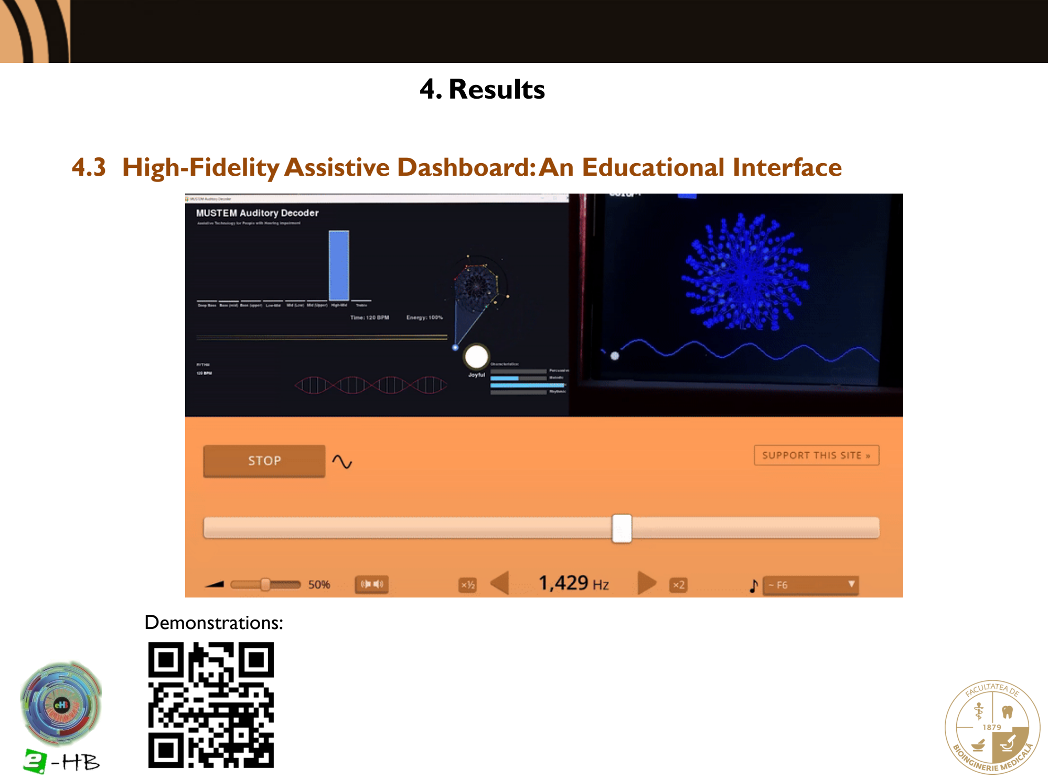
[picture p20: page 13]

Demonstrations:

### 4.3 High-Fidelity Assistive Dashboard: An Educational Interface

## 5. Limitations & Future Works

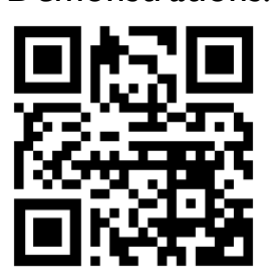
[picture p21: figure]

Demonstrations:

What We Know Works:
✓ | Scientifically-grounded translation
✓ | Real-time processing on affordable hardware
✓ | Multi-modal sensory mapping (tactile + visual)
✓ | Positive preliminary user feedback (N=7)

What Needs Refinement:
- Comprehensive user validation (IRB study ongoing)
- Noise robustness in many real-world environments
- Hardware scalability and manufacturing pipeline

VALIDATION
- IRB-approved study (N=30+, QUEST standardized)
- Multi-genre performance assessment
- Long-term usability evaluation

TECHNICAL EVOLUTION
- ARM Cortex-M4 (real-time ML inference)
- AI-based source separation
- Adaptive algorithms for diverse environments

# That's all (for now)…

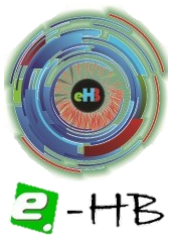
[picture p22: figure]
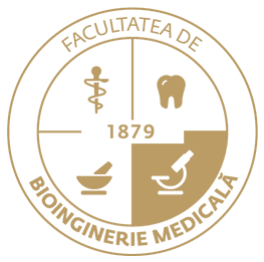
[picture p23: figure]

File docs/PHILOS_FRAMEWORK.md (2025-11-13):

# 🎭 The Central Question: Can Deaf People "Truly" Experience Music Emotionally?

## The Question That Challenges Everything

> **"How can this system truly translate the emotional experience of music to deaf individuals? Isn't emotion in music inherently difficult—perhaps impossible—to translate?"**

This question, while appearing as skepticism, actually touches on deep philosophical assumptions about sensory experience, disability, and what constitutes "authentic" engagement with art.

**Let's unpack why this question matters, why it's based on problematic assumptions, and how to answer it.**

---

## 🧠 The Philosophical Problem with the Question

### The Hidden Assumption

The question assumes there exists **one "true" emotional musical experience** that is inherently **auditory**.

This framing implies:

- Hearing people have "authentic" musical experience
- Deaf people can only have "approximated" or "translated" experience
- Non-auditory pathways are inherently "second-class"

**This is ableism disguised as scientific skepticism.**

### The Correct Reframing

The question should not be:

> "Can deaf people experience music **the same way** hearing people do?"

The question should be:

> "Can we provide systematic access to musical information through modalities that enable **meaningful, authentic emotional engagement** for deaf individuals?"

**The answer to the second question is: Yes.**

---

## 🎨 Musical Experience is Relative, Not Absolute

### Core Argument

**Musical experience is relative to individual sensory capacity.**

A person born deaf does not experience music as:

- "Auditory experience minus sound" (a deficit model)

They experience music as:

- "Structured sensory information through the modalities available to them" (a difference model)

**This is not inferior. This is different. And different is valid.**

### Why This Matters

Consider this thought experiment:

**Scenario 1: The Blind Art Critic**

> "How can a blind person truly understand a painting through verbal description? They'll never see the colors, the brushstrokes, the light. Can they really experience it emotionally?"

**Answer:** They will have a **different but equally valid** experience. It may not be visual, but it can be profoundly meaningful and emotional in its own right. To dismiss it as "not true understanding" is to impose sighted-centric assumptions.

**Scenario 2: The Synesthete Musician**

> Some people have synesthesia - they "see" colors when hearing sounds, or "taste" words. Is their musical experience "inferior" because it's different from typical auditory processing?

**Answer:** Of course not. Many synesthetes report that music is **even richer** for them because of additional sensory layers.

**Scenario 3: The Deaf Music Experiencer**

> A deaf person experiences music through vibrotactile and visual modalities. Is this "inferior" to auditory experience?

**Answer:** No. It is **authentic to their perceptual reality**. And it may even access sensory dimensions that are **more developed** in deaf individuals than in hearing people.

---

## 🧬 Neuroscience Supports Alternative Musical Pathways

### Cross-Modal Plasticity in Deaf Individuals

Research in neuroplasticity demonstrates that deaf individuals' brains **reorganize** to optimize available sensory modalities:

#### Key Findings:

1. **Auditory cortex is not idle**
    - In deaf individuals, the "auditory" cortex is recruited for **visual and tactile processing**
    - These areas process rhythm, temporal patterns, and spatial information through alternative modalities
2. **Enhanced sensory capabilities**
    - Deaf individuals often have **superior peripheral vision** compared to hearing individuals
    - **Increased tactile sensitivity** and spatial awareness
    - **More efficient visual processing of rhythmic patterns**
3. **Musical structure processing**
    - fMRI studies show deaf individuals process **musical rhythm** in similar brain regions as hearing individuals
    - The **limbic system** (emotion processing) activates regardless of sensory input modality
    - **Emotional response to music does not require auditory input**

#### Implication for MUSTEM:

When we provide musical information via **tactile + visual** modalities, we are feeding **sensory channels that may be MORE developed** in deaf individuals than in hearing people.

**We're not providing "second-best" access. We're providing access through optimized pathways.**

---

## Real-World Evidence: Deaf Musicians and Music Experiencers

### Case Study 1: Evelyn Glennie - World-Renowned Deaf Percussionist

**Dame Evelyn Glennie** is profoundly deaf and one of the world's most celebrated percussionists.

In her famous essay _"Hearing Essay"_ (1993), she wrote:

> **"Hearing is basically a specialized form of touch. Sound is simply vibrating air which the ear picks up and converts to electrical signals... For some reason we tend to make a distinction between hearing a sound and feeling a vibration, in reality they are the same thing."**

#### What This Means:

- **Hearing IS touch** - just through specialized receptors (cochlear hair cells)
- **Tactile vibration IS hearing** - just through skin mechanoreceptors
- The distinction is **anatomical**, not experiential
- Both pathways carry **the same information**: frequency, amplitude, temporal patterns

**Glennie describes profound emotional connection to music.** No one questions whether her experience is "true" - yet she accesses music non-auditorily.

---

### Case Study 2: Shaheem Sanchez - Deaf Professional Dancer

**Shaheem Sanchez** is a profoundly deaf dancer who performs to music by:

- Feeling **bass vibrations** through the floor via his feet
- Watching **visual cues** from other dancers and stage lighting
- **Internalizing rhythm** through body movement

He describes his connection to music as:

> **"Deeply emotional and spiritual. Music moves through my body in ways that hearing people might not even experience."**

**Question:** Is his emotional experience "fake" because it didn't enter through his ears?

**Answer:** Of course not. His experience is **authentic to his sensory reality**.

---

### Case Study 3: Deaf DJs and Music Producers

There are **deaf DJs** (e.g., Robbie Wilde, Troi Lee) who:

- Mix tracks by **feeling bass through subwoofers** and **watching waveforms**
- Read **visual feedback** from software to time transitions
- Use **tactile monitors** to feel beat alignment

They describe **joy, creativity, and emotional fulfillment** in music production.

**Their emotional engagement is real.** It's just accessed through different modalities.

---

## 📚 Scientific Literature Supporting Modality-Independent Musical Experience

### Key Research Papers:

#### 1. **Darrow, A. A. (2006). "The Role of Music in Deaf Culture: Deaf Students' Perception of Emotion in Music"**

- **Finding:** Deaf students who had access to structured musical experiences (vibration, visual, rhythm) developed:
    - Aesthetic appreciation of music
    - Emotional responses comparable to hearing peers
    - Individual musical preferences
- **Conclusion:** _"Musical experience is not dependent on hearing."_

---

#### 2. **Petitto, L. A., et al. (2000). "Speech-like cerebral activity in profoundly deaf people processing signed languages"**

- **Finding:** Deaf individuals' brains process **rhythm and temporal patterns** in language (sign language) using areas typically associated with auditory processing
- **Implication:** The brain cares about **patterns and structure**, not the sensory modality delivering them

---

#### 3. **Finney, E. M., et al. (2001). "Visual stimuli activate auditory cortex in the deaf"**

- **Finding:** In deaf individuals, the auditory cortex responds to **visual stimuli** with temporal structure (flashing lights, moving patterns)
- **Implication:** "Auditory" areas are actually **temporal/rhythmic pattern processors**, not exclusively auditory

---

#### 4. **Levänen, S., & Hamdorf, D. (2001). "Feeling vibrations: enhanced tactile sensitivity in congenitally deaf humans"**

- **Finding:** Deaf individuals show **enhanced tactile sensitivity** compared to hearing controls, especially for vibrotactile stimuli in frequency ranges overlapping with speech/music
- **Implication:** Tactile musical information may be **more accessible** to deaf individuals than to hearing people

---

## 🔬 The Science of Emotion in Music (It's Not About Ears)

### What Creates Emotional Response to Music?

Music evokes emotion through **structural features**, not through the specific sensory modality:

#### Key Emotional Triggers in Music:

1. **Rhythm and tempo**
    - Fast tempo → excitement, joy
    - Slow tempo → calm, sadness
    - **Accessible through:** auditory, tactile, visual (tempo visualization)
2. **Harmonic tension and resolution**
    - Dissonance → tension
    - Consonance → release
    - **Accessible through:** auditory, visual (color mapping of frequency relationships)
3. **Dynamic range (loud/soft contrasts)**
    - Crescendo → building anticipation
    - Sudden loud → surprise
    - **Accessible through:** auditory, tactile (vibration intensity), visual (size/brightness)
4. **Melodic contour**
    - Ascending melody → hope, triumph
    - Descending melody → melancholy
    - **Accessible through:** auditory, visual (spiral growth patterns)
5. **Temporal patterns and expectation**
    - Predictable patterns → comfort
    - Unexpected changes → surprise
    - **Accessible through:** any modality that preserves temporal structure

---

### The Neuroscience of Musical Emotion:

**Where does emotional processing happen?**

- **Limbic system** (amygdala, hippocampus) - processes emotional significance
- **Nucleus accumbens** - reward processing ("chills" from music)
- **Prefrontal cortex** - emotional regulation and interpretation

**Critical point:** These regions respond to **structured sensory input with temporal and relational patterns**, regardless of whether that input came from:

- Auditory cortex
- Somatosensory cortex (touch)
- Visual cortex

**The emotional response doesn't care about the sensory modality. It cares about the patterns.**

---

## 🎯 MUSTEM's Approach: Preserving Musical Structure Across Modalities

### What We Preserve (And Why It Matters)

MUSTEM doesn't attempt to "replicate hearing." Instead, it **preserves the structural features of music** that enable emotional engagement:

#### 1. **Frequency Relationships → Logarithmic Color Mapping**

- **Musical property:** Octave equivalence (notes separated by octaves sound "similar")
- **MUSTEM implementation:** Logarithmic frequency-to-hue mapping based on 12-tone equal temperament
- **Result:** Visually similar colors for notes separated by octaves
- **Emotional access:** Harmonic relationships preserved visually

#### 2. **Rhythmic Patterns → Spatial Tactile Distribution**

- **Musical property:** Rhythm as temporal structure of accents
- **MUSTEM implementation:** 4-channel vibrotactile system mapping frequency bands (kick, bass, voice, treble) to spatially separated motors
- **Result:** Rhythmic events felt as distinct spatial-temporal patterns
- **Emotional access:** Groove, pulse, and drive

#### 3. **Intensity Dynamics → Stevens' Power Law Scaling**

- **Musical property:** Dynamic range (soft/loud contrasts)
- **MUSTEM implementation:** Psychoacoustic scaling (exponent 0.67) for both tactile and visual intensity
- **Result:** Natural-feeling intensity changes that preserve emotional dynamics
- **Emotional access:** Tension, release, climax

#### 4. **Temporal Evolution → Phyllotaxis Spiral Growth**

- **Musical property:** Music unfolds over time
- **MUSTEM implementation:** Growing spiral pattern (golden angle phyllotaxis)
- **Result:** Visual representation of temporal evolution with natural aesthetic
- **Emotional access:** Anticipation, development, resolution

---

## 💡 The Core Insight: Different ≠ Inferior

### The Relativity of Sensory Experience

A person born deaf does not experience their life as "missing something." They experience life **through the sensory modalities they have**.

Similarly:

- A deaf person experiencing music through MUSTEM is not experiencing "music minus sound"
- They are experiencing **music through their authentic sensory pathways**

**This is not a compromise. This is simply how their perceptual system engages with musical structure.**

### Analogy: Color Blindness

Consider someone with red-green color blindness viewing a painting:

**Wrong question:**

> "Can they **truly** appreciate the painting if they can't see red?"

**Right question:**

> "Do they experience the painting in a way that is meaningful to them?"

**Answer:** Yes. Their experience is different, but it's not "less valid" - it's simply **their experience**.

---

## 🌍 Challenging Hearing-Centric Assumptions

### The Ableism Embedded in the Question

When we ask "_Can deaf people truly experience music emotionally?_" we reveal assumptions:

1. **Auditory experience is the standard**
    - Implies all other modalities are approximations
2. **Emotional validity requires auditory input**
    - Ignores that emotion emerges from **pattern processing**, not ears
3. **Deaf experience is inherently deficient**
    - Positions deafness as lack, rather than difference

**These assumptions are ableist.**

---

### A Better Framework: Co-Design and User Agency

**Who decides if a musical experience is "emotionally valid"?**

**Not researchers. Not hearing people. The deaf users themselves.**

MUSTEM's validation must center **deaf individuals' lived experience**:

- Do they find it meaningful?
- Does it create emotional responses?
- Does it enhance their engagement with music?

**Their answers define validity, not comparison to hearing experience.**

## 🌟 Final Reflection

The question "_Can deaf people truly experience music emotionally?_" is not a question about deaf people's capacity.

**It's a question about our assumptions.**

When we assume auditory experience is the standard, we reveal more about **our biases** than about musical experience itself.

**MUSTEM doesn't make deaf people experience music "like hearing people."**

**MUSTEM enables deaf people to experience music authentically, through their own sensory reality.**

**And that's not just valid - that's beautiful.**

## 📚 References

- Darrow, A. A. (2006). The role of music in deaf culture: Deaf students' perception of emotion in music. _Journal of Music Therapy_, 43(1), 2-15.
- Finney, E. M., Fine, I., & Dobkins, K. R. (2001). Visual stimuli activate auditory cortex in the deaf. _Nature Neuroscience_, 4(12), 1171-1173.
- Glennie, E. (1993). _Hearing Essay_. Retrieved from [https://www.evelyn.co.uk/hearing-essay/](https://www.evelyn.co.uk/hearing-essay/)
- Levänen, S., & Hamdorf, D. (2001). Feeling vibrations: enhanced tactile sensitivity in congenitally deaf humans. _Neuroscience Letters_, 301(1), 75-77.
- Petitto, L. A., Zatorre, R. J., Gauna, K., Nikelski, E. J., Dostie, D., & Evans, A. C. (2000). Speech-like cerebral activity in profoundly deaf people processing signed languages: Implications for the neural basis of human language. _Proceedings of the National Academy of Sciences_, 97(25), 13961-13966.

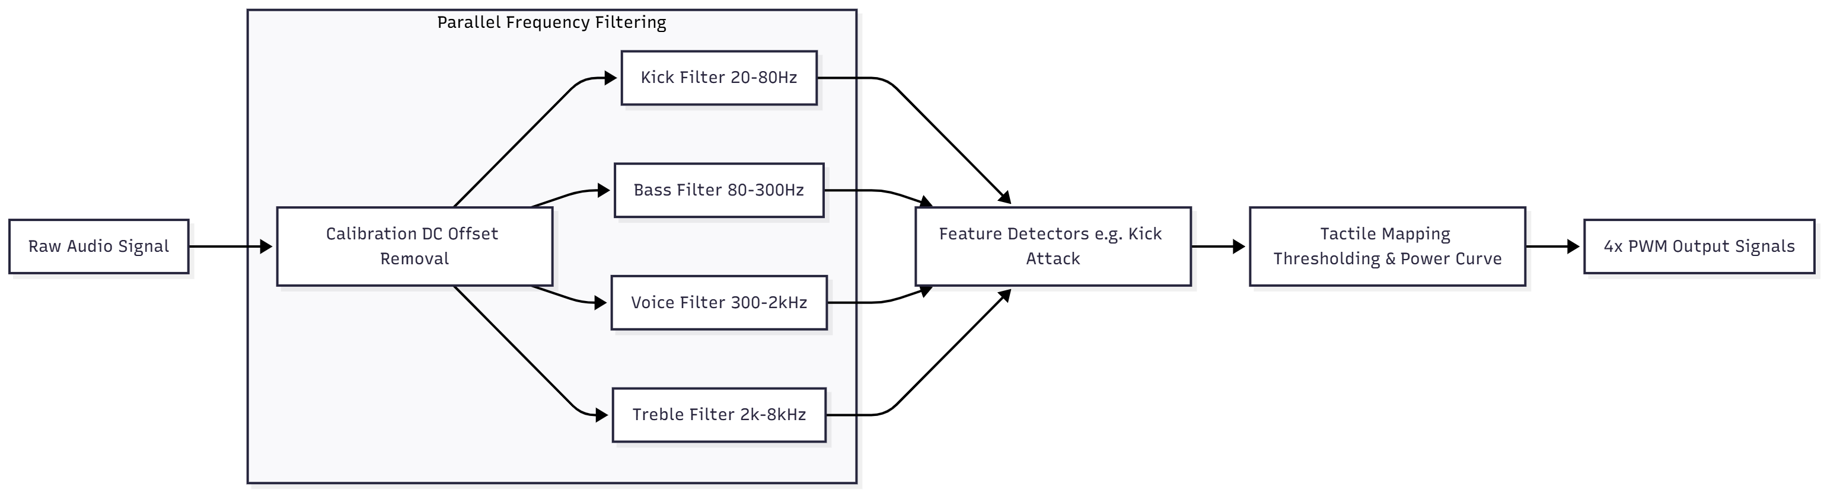
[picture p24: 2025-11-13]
hardware/schematics/flow_tactile.png

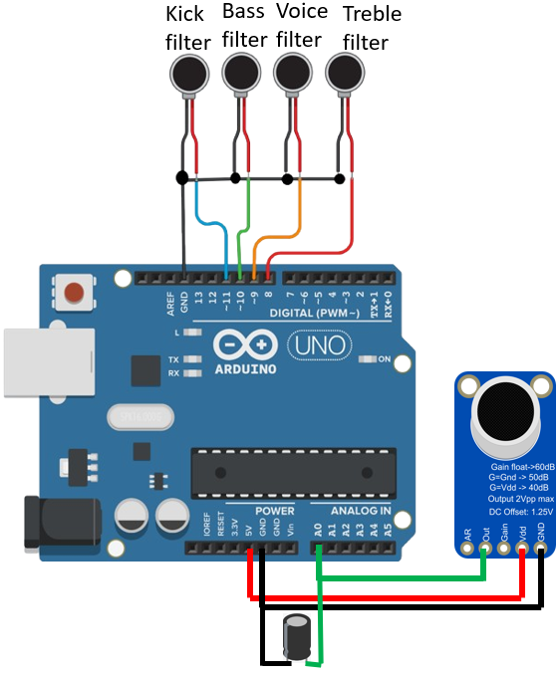
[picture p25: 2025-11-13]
hardware/schematics/uno_motors.png

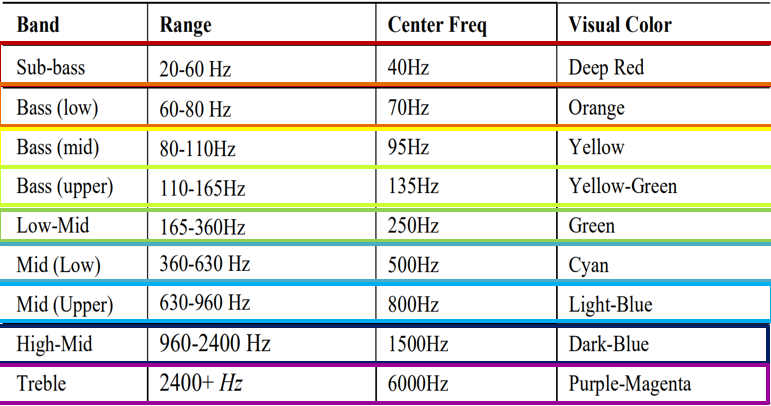
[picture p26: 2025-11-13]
docs/images/color_mapping.png

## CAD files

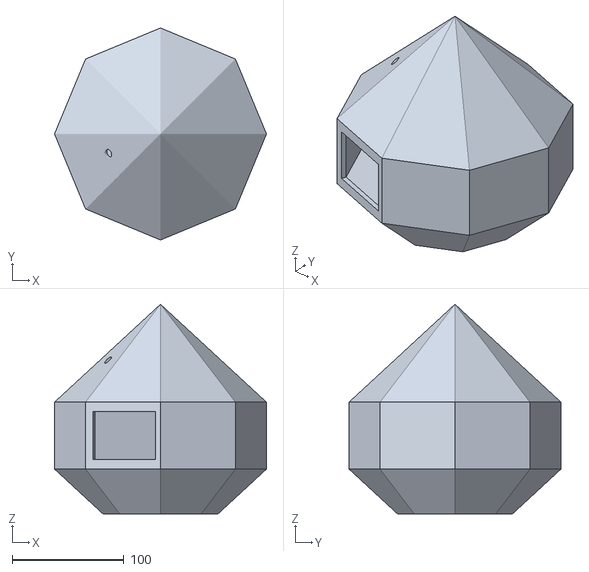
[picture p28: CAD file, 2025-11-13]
hardware/3d_models/mustem3dmodel.obj
190.0 x 190.0 x 187.8

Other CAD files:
hardware/3d_models/mustem3dmodel.dwg
hardware/3d_models/mustem3dmodel.f3d

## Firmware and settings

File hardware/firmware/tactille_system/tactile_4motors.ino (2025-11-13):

// SISTEMA MUSICAL TÁTIL - 4 MOTORES
// Tecnologia Assistiva para Deficientes Auditivos
// Separação em 4 faixas de frequência para experiência imersiva

const int micPin = A1;
const int ledPin = 3;

// === 4 MOTORES - SEPARAÇÃO REFORMULADA ===
const int motorKickPin = 11;        // KICK/BUMBO (20-80Hz) - Batidas principais
const int motorBaixoPin = 10;       // BAIXO/BASS (80-300Hz) - Linha de baixo constante
const int motorVozPin = 9;         // VOZ/MELODIA (300-2kHz) - Vocal, guitarra, piano
const int motorAgudosPin = 8;      // AGUDOS (2k-8kHz) - Pratos, hi-hat, harmônicos

// === FILTROS REFORMULADOS ===
float filtroKick = 0.0;           // Para detectar batidas (kick/bumbo)
float filtroBaixo = 0.0;          // Para linha de baixo constante
float filtroVoz = 0.0;            // Para vocal/melodia
float filtroAgudos = 0.0;         // Para pratos/detalhes

// Coeficientes especializados
const float coefKick = 0.08;      // Muito lento = detecta kick/bumbo
const float coefBaixo = 0.30;     // Médio-rápido = linha de baixo
const float coefVoz = 0.45;       // Rápido = vocal/melodia
const float coefAgudos = 0.8;     // Muito rápido = agudos

// === DETECTORES ESPECIAIS ===
float kickBoost = 0.0;            // Boost para detecção de kick
float baixoConstante = 0.0;       // Detecta linha de baixo constante
float vozDetector = 0.0;          // Detector específico de voz
float hihatDetector = 0.0;        // Detector de hi-hat/pratos

// === VARIÁVEIS DE CONTROLE ===
int valorBase = 512;
float amplitudeAnterior = 0.0;
float vozAnterior = 0.0;
unsigned long ultimaBatida = 0;

// === INTENSIDADES DOS MOTORES ===
int intensidadeKick = 0;          // Motor kick/bumbo
int intensidadeBaixo = 0;         // Motor baixo/bass
int intensidadeVoz = 0;           // Motor voz/melodia
int intensidadeAgudos = 0;        // Motor agudos

// === THRESHOLDS REFORMULADOS ===
const float THRESHOLD_KICK = 45.0;     // Kick/bumbo (mais seletivo)
const float THRESHOLD_BAIXO = 58.0;     // Baixo (mais sensível)
const float THRESHOLD_VOZ = 52.0;      // Voz/melodia (mais sensível)
const float THRESHOLD_AGUDOS = 30.0;   // Agudos (mais sensível)

// === PARÂMETROS PARA EXPERIÊNCIA TÁTIL ===
const int INTENSIDADE_MIN = 80;        // PWM mínimo para sentir
const int INTENSIDADE_MAX_SUB = 255;   // Sub-graves = mais forte
const int INTENSIDADE_MAX_MED = 240;   // Med-graves = forte
const int INTENSIDADE_MAX_VOZ = 200;   // Voz = médio
const int INTENSIDADE_MAX_AGUDOS = 180; // Agudos = mais suave

void setup() {
  Serial.begin(115200);
  
  pinMode(motorKickPin, OUTPUT);
  pinMode(motorBaixoPin, OUTPUT);
  pinMode(motorVozPin, OUTPUT);
  pinMode(motorAgudosPin, OUTPUT);
  pinMode(ledPin, OUTPUT);
  pinMode(micPin, INPUT);
  
  Serial.println("=== SISTEMA MUSICAL TÁTIL - 4 MOTORES ===");
  Serial.println("🎵 Tecnologia Assistiva para Deficientes Auditivos");
  Serial.println();
  Serial.println("MAPEAMENTO DOS MOTORES:");
  Serial.println("Motor 1 (KICK): Bumbo, batidas principais (20-80Hz)");
  Serial.println("Motor 2 (BAIXO): Linha de baixo constante (80-300Hz)");
  Serial.println("Motor 3 (VOZ): Vocal, guitarra, melodia (300-2kHz)");
  Serial.println("Motor 4 (AGU): Pratos, hi-hat, detalhes (2k-8kHz)");
  Serial.println();
  
  // Calibração
  Serial.print("Calibrando sistema");
  long soma = 0;
  for(int i = 0; i < 150; i++) {
    soma += analogRead(micPin);
    if(i % 25 == 0) Serial.print(".");
    delay(3);
  }
  valorBase = soma / 150;
  
  Serial.println();
  Serial.print("Valor base calibrado: ");
  Serial.println(valorBase);
  Serial.println();
  Serial.println("🎶 Sistema ativo! Reproduza música para testar.");
  Serial.println("Monitor mostrará: KICK|BAIXO|VOZ|AGU + barras visuais");
  Serial.println("===============================================");
  
  delay(1000);
}

void loop() {
  // === LEITURA E PRÉ-PROCESSAMENTO ===
  int valorAtual = analogRead(micPin);
  float amplitude = abs(valorAtual - valorBase);
  
  // === FILTROS DE FREQUÊNCIA ESPECIALIZADOS ===
  
  // KICK: Ultra lento = detecta apenas batidas profundas (bumbo)
  filtroKick = filtroKick * (1.0 - coefKick) + amplitude * coefKick;
  
  // BAIXO: Velocidade média = linha de baixo constante
  filtroBaixo = filtroBaixo * (1.0 - coefBaixo) + amplitude * coefBaixo;
  
  // VOZ: Detecta variações médias = vocal, melodias
  float deltaVoz = amplitude - vozAnterior;
  filtroVoz = filtroVoz * (1.0 - coefVoz) + abs(deltaVoz) * coefVoz;
  vozAnterior = amplitude;
  
  // AGUDOS: Muito rápido = pratos, hi-hat, harmônicos
  filtroAgudos = filtroAgudos * (1.0 - coefAgudos) + amplitude * coefAgudos;
  
  // === DETECTORES ESPECIAIS ===
  
  // Detector de KICK: Pico súbito E filtro lento alto
  float deltaAmplitude = amplitude - amplitudeAnterior;
  if(deltaAmplitude > 35.0 && filtroKick > 8.0 && 
     (millis() - ultimaBatida) > 150) {  // Intervalo maior entre kicks
    kickBoost = 30.0;  // Boost para kick
    ultimaBatida = millis();
  }
  kickBoost *= 0.8;  // Decay médio
  
  // Detector de BAIXO CONSTANTE: Nível médio estável
  if(filtroBaixo > 8.0 && filtroBaixo < 40.0) {
    baixoConstante = min(baixoConstante + 3.0, 25.0);
  }
  baixoConstante *= 0.92;  // Decay lento
  
  // Detector de VOZ: Variações na faixa média
  if(filtroVoz > 8.0) {
    vozDetector = min(vozDetector + 4.0, 30.0);
  }
  vozDetector *= 0.85;
  
  // Detector de HI-HAT: Agudos puros sem graves
  if(filtroAgudos > 25.0 && filtroKick < 10.0) {
    hihatDetector = min(hihatDetector + 6.0, 20.0);
  }
  hihatDetector *= 0.75;
  
  amplitudeAnterior = amplitude;
  
  // === CÁLCULO DAS INTENSIDADES FINAIS ===
  
  float nivelKick = filtroKick + kickBoost;           // Kick = filtro lento + boosts
  float nivelBaixo = filtroBaixo + baixoConstante;    // Baixo = filtro médio + constante
  float nivelVoz = filtroVoz + vozDetector;           // Voz = variações médias
  float nivelAgudos = filtroAgudos + hihatDetector;   // Agudos = filtro rápido + hi-hat
  
  // === CONTROLE DOS MOTORES ===
  
  // KICK/BUMBO (apenas para batidas principais)
  if(nivelKick > THRESHOLD_KICK) {
    float norm = constrain(nivelKick - THRESHOLD_KICK, 0, 40) / 40.0;
    norm = pow(norm, 0.9);
    intensidadeKick = INTENSIDADE_MIN + (norm * (INTENSIDADE_MAX_SUB - INTENSIDADE_MIN));
  } else {
    intensidadeKick = 0;
  }
  
  // BAIXO (linha de baixo constante)
  if(nivelBaixo > THRESHOLD_BAIXO) {
    float norm = constrain(nivelBaixo - THRESHOLD_BAIXO, 0, 50) / 50.0;
    norm = pow(norm, 0.7);
    intensidadeBaixo = INTENSIDADE_MIN + (norm * (INTENSIDADE_MAX_MED - INTENSIDADE_MIN));
  } else {
    intensidadeBaixo = 0;
  }
  
  // VOZ/MELODIA
  if(nivelVoz > THRESHOLD_VOZ) {
    float norm = constrain(nivelVoz - THRESHOLD_VOZ, 0, 45) / 45.0;
    norm = pow(norm, 0.8);
    intensidadeVoz = INTENSIDADE_MIN + (norm * (INTENSIDADE_MAX_VOZ - INTENSIDADE_MIN));
  } else {
    intensidadeVoz = 0;
  }
  
  // AGUDOS
  if(nivelAgudos > THRESHOLD_AGUDOS) {
    float norm = constrain(nivelAgudos - THRESHOLD_AGUDOS, 0, 35) / 35.0;
    norm = pow(norm, 0.75);
    intensidadeAgudos = INTENSIDADE_MIN + (norm * (INTENSIDADE_MAX_AGUDOS - INTENSIDADE_MIN));
  } else {
    intensidadeAgudos = 0;
  }
  
  // === ACIONAMENTO DOS MOTORES ===
  analogWrite(motorKickPin, intensidadeKick);
  analogWrite(motorBaixoPin, intensidadeBaixo);
  analogWrite(motorVozPin, intensidadeVoz);
  analogWrite(motorAgudosPin, intensidadeAgudos);
  
  // LED indicador (intensidade máxima)
  int ledLevel = max(max(intensidadeKick, intensidadeBaixo), 
                     max(intensidadeVoz, intensidadeAgudos));
  analogWrite(ledPin, ledLevel);
  
  // === MONITOR PARA TECNOLOGIA ASSISTIVA ===
  static unsigned long ultimoMonitor = 0;
  if(millis() - ultimoMonitor > 120) {  // Monitor a cada 120ms
    
    // Cabeçalho com status geral
    bool sistemaAtivo = (intensidadeKick + intensidadeBaixo + intensidadeVoz + intensidadeAgudos) > 0;
    
    Serial.print(sistemaAtivo ? "🎵 MÚSICA ATIVA " : "⏸  SILÊNCIO    ");
    
    // Valores dos motores
    Serial.print("SUB:");
    Serial.print(String(intensidadeKick).substring(0,3));
    Serial.print(" MED:");
    Serial.print(String(intensidadeBaixo).substring(0,3));
    Serial.print(" VOZ:");
    Serial.print(String(intensidadeVoz).substring(0,3));
    Serial.print(" AGU:");
    Serial.print(String(intensidadeAgudos).substring(0,3));
    
    Serial.print(" |");
    
    // Visualização tátil com barras
    int subBars = map(intensidadeKick, 0, 255, 0, 5);
    int medBars = map(intensidadeBaixo, 0, 255, 0, 5);
    int vozBars = map(intensidadeVoz, 0, 255, 0, 5);
    int aguBars = map(intensidadeAgudos, 0, 255, 0, 5);
    
    // Sub-graves = █ (mais forte)
    for(int i = 0; i < 5; i++) Serial.print(i < subBars ? "█" : ".");
    Serial.print("|");
    
    // Med-graves = ▓
    for(int i = 0; i < 5; i++) Serial.print(i < medBars ? "▓" : ".");
    Serial.print("|");
    
    // Voz = ▒
    for(int i = 0; i < 5; i++) Serial.print(i < vozBars ? "▒" : ".");
    Serial.print("|");
    
    // Agudos = ░
    for(int i = 0; i < 5; i++) Serial.print(i < aguBars ? "░" : ".");
    
    // Detectores especiais
    if(kickBoost > 5) Serial.print(" 🥁KICK");
    if(baixoConstante > 5) Serial.print(" 🎸BAIXO");
    if(hihatDetector > 5) Serial.print(" ✨HIHAT");
    
    Serial.println();
    ultimoMonitor = millis();
  }
  
  delay(8); 
}

/*
SEPARAÇÃO EM 4 FAIXAS:
1. SUB-GRAVES (20-80Hz): Bateria, sub-bass - VIBRAÇÃO MAIS INTENSA
2. MED-GRAVES (80-250Hz): Bumbo, baixo - VIBRAÇÃO FORTE  
3. VOZ/MELODIA (250-2kHz): Vocal, guitarra, piano - VIBRAÇÃO EXPRESSIVA
4. AGUDOS (2k-8kHz): Pratos, hi-hat - VIBRAÇÃO DELICADA

RECURSOS ESPECIAIS:
- Detectores de instrumentos específicos (kick, snare, hi-hat)
- Intensidades calibradas para experiência tátil otimizada
- Curvas não-lineares para maior expressividade
- Monitor visual detalhado para acompanhamento

POSICIONAMENTO SUGERIDO DOS MOTORES:
- SUB-GRAVES: Peito/costas (graves se sentem no corpo todo)
- MED-GRAVES: Abdômen (bumbo e baixo)
- VOZ: Braços/ombros (melodias)
- AGUDOS: Pulsos/mãos (detalhes delicados)

RESULTADO ESPERADO:
- Música pop: Todos motores ativos em harmonia
- Música eletrônica: Sub e med-graves predominantes
- Balada: Voz proeminente com acompanhamento suave
- Rock: Med-graves (bateria) + voz (guitarra) intensos

AJUSTES POSSÍVEIS:
- THRESHOLD_*: Sensibilidade de cada faixa
- INTENSIDADE_MAX_*: Força máxima de cada motor
- Coeficientes dos filtros: Separação das frequências
*/

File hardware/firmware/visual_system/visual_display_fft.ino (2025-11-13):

// #include <MCUFRIEND_kbv.h>
// #include <Adafruit_GFX.h>
// #include <arduinoFFT.h>

// MCUFRIEND_kbv tft;

// // ============================================================================
// // PARÂMETROS CIENTÍFICOS FUNDAMENTADOS
// // ============================================================================

// // Audio Sampling (baseado em Teorema de Nyquist)
// #define SAMPLING_FREQ 4000              // 10kHz sample rate
// #define FFT_SAMPLES 512                  // 128-point FFT
// #define SAMPLE_PERIOD_US (1000000UL / SAMPLING_FREQ)  // 100 µs

// // Screen
// #define SCREEN_WIDTH 320
// #define SCREEN_HEIGHT 240
// #define ELETRETO_PIN A6

// #ifndef log2
//   #define log2(x) (log(x) / 0.69314718056)
// #endif

// // Psychoacoustic Frequency Bands (Fletcher-Munson + Bark scale)
// struct FrequencyBands {
//   float SUBBASS_LOW = 20.0;
//   float SUBBASS_HIGH = 60.0;
//   float BASS_LOW = 60.0;
//   float BASS_HIGH = 250.0;
//   float LOWMID_LOW = 250.0;
//   float LOWMID_HIGH = 500.0;
//   float MID_LOW = 500.0;
//   float MID_HIGH = 2000.0;
//   float HIGHMID_LOW = 2000.0;
//   float HIGHMID_HIGH = 4000.0;
//   float TREBLE_LOW = 4000.0;
//   float TREBLE_HIGH = 8000.0;
// };

// FrequencyBands FREQ_BANDS;

// // Stevens Power Law for haptic mapping
// const float STEVENS_EXPONENT = 0.67;

// // Beat detection parameters (based on literature)
// const float ONSET_THRESHOLD_MULTIPLIER = 1.5;     // k*sigma above mean
// const unsigned long MIN_ONSET_INTERVAL_MS = 150;  // 400 BPM max

// // Silence detection
// float SILENCE_ENERGY_THRESHOLD = 50.0;      // Calibrated for electret mic
// const unsigned long SILENCE_TIMEOUT_MS = 2000;


// bool thresholdCalibrated = false;
// float ambientNoiseLevel = 0.0;

// // ============================================================================
// // FFT BUFFERS AND INSTANCE
// // ============================================================================

// float vReal[FFT_SAMPLES];
// float vImag[FFT_SAMPLES];
// ArduinoFFT<float> FFT(vReal, vImag, FFT_SAMPLES, SAMPLING_FREQ);

// // ============================================================================
// // DATA STRUCTURES
// // ============================================================================

// struct AudioAnalysis {
//   float dominantFreq;
//   float peakMagnitude;
//   float totalEnergy;
//   float rms;
//   unsigned long lastUpdate;
//   bool isActive;
// };

// struct SpectrumData {
//   float bands[6];           // 6 psycoacoustic bands
//   float smoothedBands[6];
//   float smoothingFactor;    // IIR filter coefficient
//   unsigned long lastUpdate;
  
//   SpectrumData() : smoothingFactor(0.3) {
//     for (int i = 0; i < 6; i++) {
//       bands[i] = 0.0;
//       smoothedBands[i] = 0.0;
//     }
//     lastUpdate = 0;
//   }
// };

// struct BeatDetector {
//   float energyHistory[16];
//   int historyIndex;
//   float currentStrength;
//   unsigned long lastOnset;
//   unsigned long lastAnalysis;
  
//   BeatDetector() : historyIndex(0), currentStrength(0.0), 
//                    lastOnset(0), lastAnalysis(0) {
//     for (int i = 0; i < 16; i++) {
//       energyHistory[i] = 0.0;
//     }
//   }
  
//   bool detectOnset(float currentEnergy, unsigned long currentTime) {
//     // Calculate mean
//     float mean = 0.0;
//     for (int i = 0; i < 16; i++) {
//       mean += energyHistory[i];
//     }
//     mean /= 16.0;
    
//     // Calculate standard deviation
//     float variance = 0.0;
//     for (int i = 0; i < 16; i++) {
//       float diff = energyHistory[i] - mean;
//       variance += diff * diff;
//     }
//     float stdDev = sqrt(variance / 16.0);
    
//     // Adaptive threshold
//     float threshold = mean + ONSET_THRESHOLD_MULTIPLIER * stdDev;
    
//     // Detect onset
//     bool isOnset = false;
//     if (currentEnergy > threshold && 
//         (currentTime - lastOnset) > MIN_ONSET_INTERVAL_MS) {
//       isOnset = true;
//       currentStrength = min(1.0, (currentEnergy - mean) / (stdDev + 0.1));
//       lastOnset = currentTime;
//     } else {
//       currentStrength *= 0.85; // Exponential decay
//     }
    
//     // Update history
//     energyHistory[historyIndex] = currentEnergy;
//     historyIndex = (historyIndex + 1) % 16;
    
//     return isOnset;
//   }
// };

// struct WindingVisualizer {
//   float phase;
//   float rotationSpeed;
//   int pointCount;
//   unsigned long lastUpdate;
//   unsigned long lastClear;
  
//   // Phyllotaxis parameters (Golden Ratio spiral)
//   const float GOLDEN_ANGLE = 2.39996323; // 137.5° in radians
//   const int MAX_POINTS = 200;
  
//   WindingVisualizer() : phase(0.0), rotationSpeed(0.0), pointCount(0),
//                         lastUpdate(0), lastClear(0) {}
// };

// // Global instances
// AudioAnalysis audio;
// SpectrumData spectrum;
// BeatDetector beatDetect;
// WindingVisualizer winding;

// // Silence state
// bool isInSilence = false;
// unsigned long lastAudioDetectedTime = 0;

// // Timing intervals (empirically optimized for balance)
// const unsigned long FFT_INTERVAL_MS = 50;         // 20 Hz (FFT is expensive)
// const unsigned long SPECTRUM_UPDATE_MS = 100;     // 10 Hz
// const unsigned long WINDING_UPDATE_MS = 40;       // 25 Hz
// const unsigned long BEAT_DETECT_MS = 100;         // 10 Hz
// const unsigned long WINDING_CLEAR_MS = 8000;      // 8 seconds

// // ============================================================================
// // SETUP
// // ============================================================================


// // ============================================================================
// // AUTO-CALIBRATION
// // ============================================================================

// void calibrateSilenceThreshold() {
//   Serial.println("\n=== CALIBRANDO THRESHOLD DE SILÊNCIO ===");
//   Serial.println("Mantenha o ambiente SILENCIOSO por 3 segundos...");
  
//   tft.fillScreen(0x0000);
//   tft.setTextSize(2);
//   tft.setTextColor(0xFFE0); // Yellow
//   tft.setCursor(30, 100);
//   tft.print("Calibrando...");
//   tft.setCursor(20, 130);
//   tft.print("Mantenha silencio");
  
//   delay(1000); // Dar tempo para estabilizar
  
//   // Coletar amostras de ruído ambiente
//   const int NUM_SAMPLES = 30;
//   float noiseSamples[NUM_SAMPLES];
  
//   for (int i = 0; i < NUM_SAMPLES; i++) {
//     // Fazer FFT simples
//     unsigned long startTime = micros();
    
//     for (int j = 0; j < FFT_SAMPLES; j++) {
//       vReal[j] = analogRead(ELETRETO_PIN);
//       vImag[j] = 0.0;
//       while (micros() - startTime < (j + 1) * SAMPLE_PERIOD_US) {}
//     }
    
//     // Remove DC offset
//     float dcOffset = 0.0;
//     for (int j = 0; j < FFT_SAMPLES; j++) {
//       dcOffset += vReal[j];
//     }
//     dcOffset /= FFT_SAMPLES;
    
//     for (int j = 0; j < FFT_SAMPLES; j++) {
//       vReal[j] -= dcOffset;
//     }
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

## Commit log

2025-11-13 Remove unused files and modules, including Arduino sketches, configuration files, and audio processing utilities. Add a new image asset for documentation. Update environment dependencies to include p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
2025-11-13 Refactor code structure for improved readability and maintainability
    [mustem3dmodel.dwg, mustem3dmodel.f3d, mustem3dmodel.obj]
2025-11-13 Revise README to emphasize the philosophical framework of music experience for deaf individuals, addressing ableism and promoting sensory diversity.
2025-11-13 Add new schematic diagrams for hardware components
    - Added diagram.PNG for overall hardware schematic.
    - Added flow_tactile.png for tactile flow representation.
    - Added integrated_system.png for integrated system overview.
    - Added mega_LCD_eletreto.png for mega LCD schematic.
    - Added uno_motors.png for Arduino Uno motor connections.
    [mustem3dmodel.dwg, mustem3dmodel.f3d, mustem3dmodel.obj]

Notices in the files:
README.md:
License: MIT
